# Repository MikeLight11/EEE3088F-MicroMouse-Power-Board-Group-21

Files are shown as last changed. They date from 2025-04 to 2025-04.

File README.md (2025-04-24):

# Micromouse Power Subsystem

## Overview
This repository contains the design files and documentation for the power subsystem of a micromouse robot developed for the EEE3088F 2025 course project. The micromouse is an autonomous robot designed to navigate through and solve mazes efficiently. The power subsystem is responsible for powering the entire micromouse, including battery management, motor control, and regulated power distribution.

## Project Description
The micromouse project consists of four main modules:
- Motherboard (provided)
- Processor (provided)
- Sensing system (provided)
- Power subsystem (this project)

Our power subsystem is designed to meet the following key requirements:
- Power and control 4 motors bidirectionally
- Provide battery monitoring via INA219 on I2C bus
- Charge the battery from 9V input with dual charging modes
- Integrate USB-C with 9V output
- Provide external load switching capabilities
- Deliver regulated 3.3V and 5V outputs
- Include ON/OFF switch with ultra-low power standby mode

## Features
- **Battery Management**: Uses BQ24074 charge controller for efficient Li-Ion battery charging with configurable charging currents (200mA standard, 600mA fast charging)
- **Motor Control**: H-bridges for bidirectional control of up to 4 motors
- **Power Regulation**: Provides stable 3.3V and 5V power rails
- **Load Switching**: Two external load switches capable of handling 1A each
- **Battery Monitoring**: INA219 current/voltage monitoring over I2C
- **Power-saving Mode**: <30μA current draw in OFF state
- **USB-C Integration**: Supports power input through USB-C

## Repository Structure
- `/Docs` - Documentation including the report
- `/Final Schematic and PCB` - KiCad schematic files and PCB design files
- `/Footprint Library` - Contains all imported footprints 
- `/Gerbers` - Production Gerber files
- `/Old Schematics` - Backup KiCad schematic files 
- `/Production files` - Contains the zip file of the Gerbers, the BOM and CPL (JLCPCB Submission files)

## Hardware Specifications
- Dimensions: Maximum 82mm × 60mm
- Battery: 3.7V 800mAh LiPo
- Input Voltage: 9V or USB-C
- Output Voltages: 3.3V (300mA max) and 5V (1.5A max)
- PCB Connector: 2x16 (2.54mm pin pitch) header connecting to the motherboard

## 3D render of PCB
WhatsApp Image 2025-03-28 at 17 49 13_c2ff8d84

## Contributors
- Michael Lighton (LGHMIC003)
- Michael Smith (SMTMIC078)

## Acknowledgments
- University of Cape Town, Department of Electrical Engineering
- EEE3088F course staff

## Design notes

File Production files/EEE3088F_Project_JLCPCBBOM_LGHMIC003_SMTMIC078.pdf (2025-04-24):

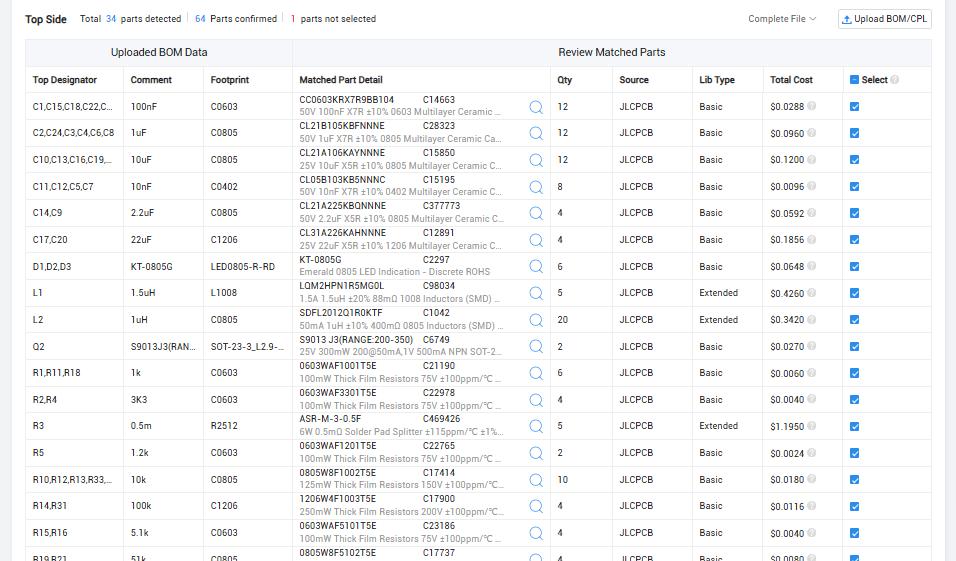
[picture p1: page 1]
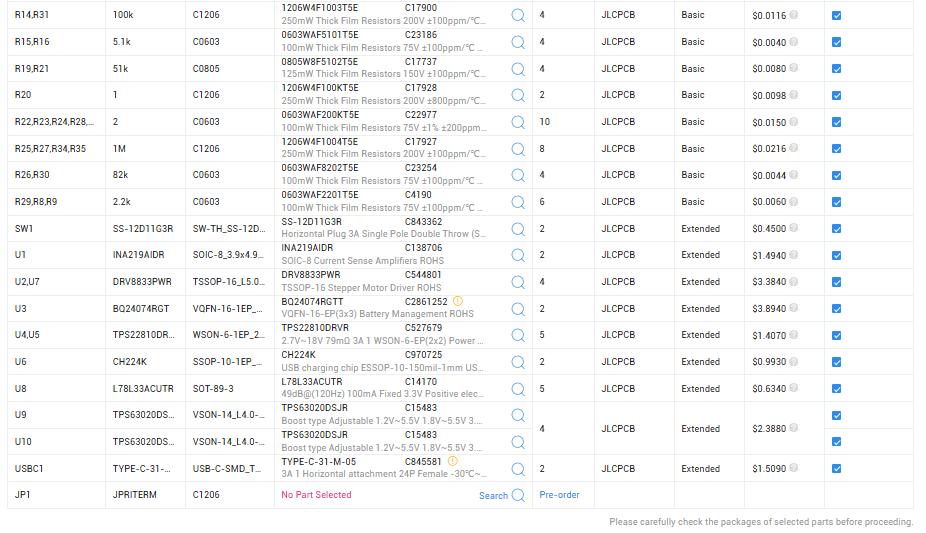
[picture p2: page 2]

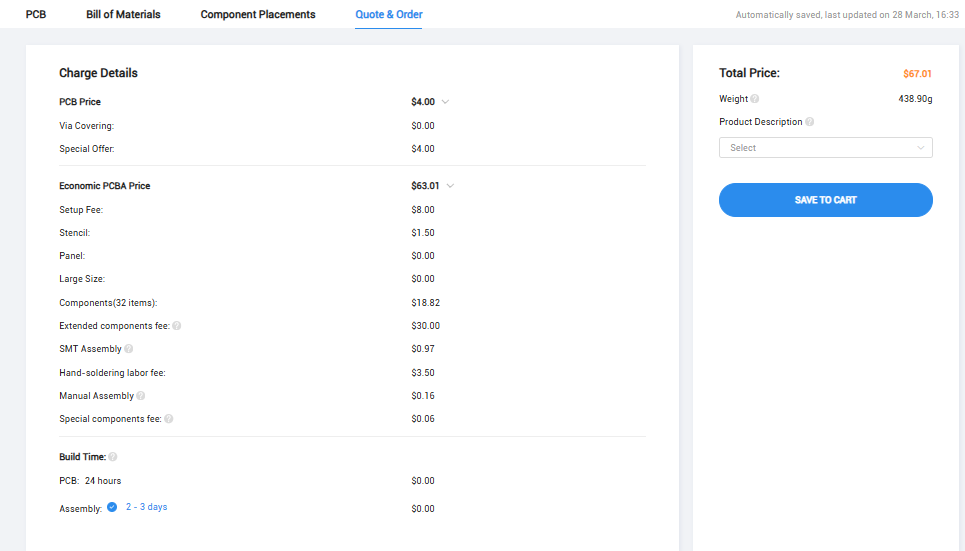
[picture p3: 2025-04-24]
Production files/EEE3088F_Project_JLCPCBacceptance_LGHMIC003_SMTMIC078.png

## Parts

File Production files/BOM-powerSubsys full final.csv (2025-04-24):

Comment | Designator | Footprint | LCSC | Quantity
1uH | L2 | C0805 | C1042 | 1
22uF | C17,C20 | C1206 | C12891 | 2
INA219AIDR | U1 | SOIC-8_3.9x4.9mm_P1.27mm | C138706 | 1
L78L33ACUTR | U8 | SOT-89-3 | C14170 | 1
100nF | C1,C15,C18,C22,C23,C25 | C0603 | C14663 | 6
10nF | C11,C12,C5,C7 | C0402 | C15195 | 4
10uF | C10,C13,C16,C19,C21,C26 | C0805 | C15850 | 6
10k | R10,R12,R13,R33,R7 | C0805 | C17414 | 5
51k | R19,R21 | C0805 | C17737 | 2
100k | R14,R31 | C1206 | C17900 | 2
1M | R25,R27,R34,R35 | C1206 | C17927 | 4
1 | R20 | C1206 | C17928 | 1
1k | R1,R11,R18 | C0603 | C21190 | 3
1.2k | R5 | C0603 | C22765 | 1
KT-0805G | D1,D2,D3 | LED0805-R-RD | C2297 | 3
2 | R22,R23,R24,R28,R32 | C0603 | C22977 | 5
3K3 | R2,R4 | C0603 | C22978 | 2
5.1k | R15,R16 | C0603 | C23186 | 2
82k | R26,R30 | C0603 | C23254 | 2
1uF | C2,C24,C3,C4,C6,C8 | C0805 | C28323 | 6
2.2uF | C14,C9 | C0805 | C377773 | 2
2.2k | R29,R8,R9 | C0603 | C4190 | 3
0.5m | R3 | R2512 | C469426 | 1
TPS22810DRVR | U4,U5 | WSON-6-1EP_2x2mm_P0.65mm_EP1x1.6mm | C527679 | 2
DRV8833PWR | U2,U7 | TSSOP-16_L5.0-W4.4-P0.65-LS6.4-BL | C544801 | 2
S9013 J3(RANGE:200-350) | Q2 | SOT-23-3_L2.9-W1.3-P1.90-LS2.4-BR | C6749 | 1
SS-12D11G3R | SW1 | SW-TH_SS-12D11L3 | C843362 | 1
TYPE-C-31-M-05 | USBC1 | USB-C-SMD_TYPE-C-USB-19 | C845581 | 1
CH224K | U6 | SSOP-10-1EP_3.9x4.9mm_P1mm_EP2.1x3.3mm | C970725 | 1
1.5uH | L1 | L1008 | C98034 | 1
JP RITERM | JP1 | C1206 |  | 1
TPS63020DSJR | U9 | VSON-14_L4.0-W3.0-P0.50-BL-EP_TI_DSJ |  | 1
TPS63020DSJR | U10 | VSON-14_L4.0-W3.0-P0.50-BL-EP_TI_DSJ |  | 1
BQ24074RGT | U3 | VQFN-16-1EP_3x3mm_P0.5mm_EP1.6x1.6mm |  | 1

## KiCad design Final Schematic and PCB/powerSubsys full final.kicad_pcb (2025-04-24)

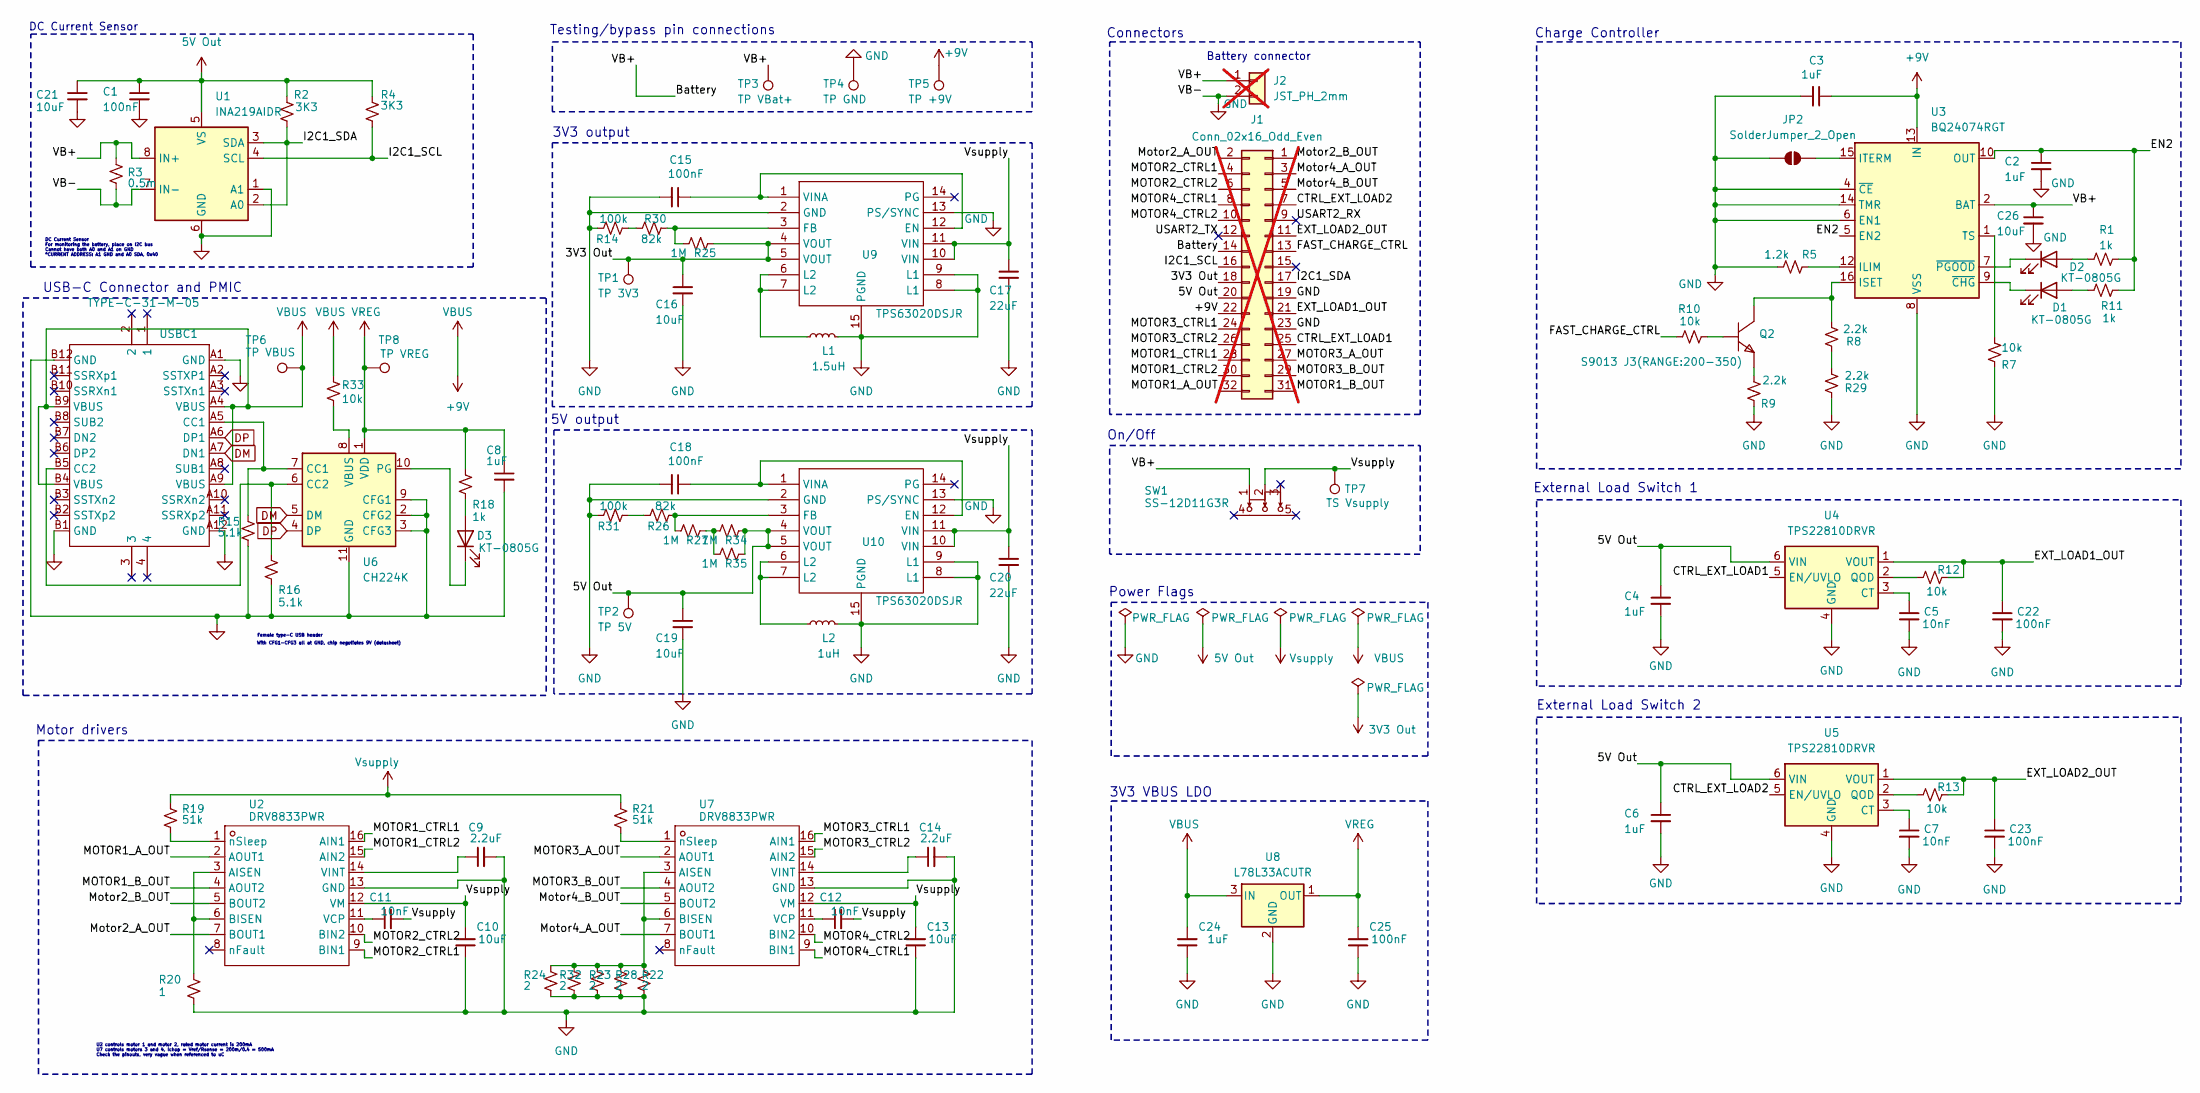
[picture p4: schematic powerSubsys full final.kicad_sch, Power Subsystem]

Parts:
C1, C15, C18, C22, C23, C25: 100nF; C0603; LCSC C14663
C2, C3, C4, C6, C8, C24: 1uF; C0805; LCSC C28323
C5, C7, C11, C12: 10nF; C0402; LCSC C15195
C9, C14: 2.2uF; C0805; LCSC C377773
C10, C13, C16, C19, C21, C26: 10uF; C0805; LCSC C15850
C17, C20: 22uF; C1206; LCSC C12891
D1, D2, D3: KT-0805G; LED0805-R-RD; LCSC C2297
J1: Conn_02x16_Odd_Even; PinHeader_2x16_P2.54mm_Vertical; not fitted
J2: JST_PH_2mm; JST_PH_S2B-PH-K_1x02_P2.00mm_Horizontal; not fitted
JP2: SolderJumper_2_Open; SolderJumper-2_P1.3mm_Open_RoundedPad1.0x1.5mm
L1: 1.5uH; L1008; LCSC C98034
L2: 1uH; C0805; LCSC C1042
Q2: S9013 J3(RANGE:200-350); SOT-23-3_L2.9-W1.3-P1.90-LS2.4-BR; MANUFACTURER PART S9013 J3(RANGE:200-350); LCSC PART NAME NPN 电流:500mA 耐压:25V H档(200-350)
R1, R11, R18: 1k; C0603; LCSC C21190
R2, R4: 3K3; C0603; LCSC C22978
R3: 0.5m; R2512; LCSC C469426
R5: 1.2k; C0603; LCSC C22765
R7, R10, R12, R13, R33: 10k; C0805; LCSC C17414
R8, R9, R29: 2.2k; C0603; LCSC C4190
R14, R31: 100k; C1206; LCSC C17900
R15, R16: 5.1k; C0603; LCSC C23186
R19, R21: 51k; C0805; LCSC C17737
R20: 1; C1206; LCSC C17928
R22, R23, R24, R28, R32: 2; C0603; LCSC C22977
R25, R27, R34, R35: 1M; C1206; LCSC C17927
R26, R30: 82k; C0603; LCSC C23254
SW1: SS-12D11G3R; SW-TH_SS-12D11L3; CURRENT RATING (DC) 3A; VOLTAGE RATING (DC) 125V; MANUFACTURER PART SS-12D11G3R; LCSC PART NAME 柄长3mm 弯插双档 滑动开关
TP1: TP 3V3; TestPoint_Pad_D1.5mm
TP2: TP 5V; TestPoint_Pad_D1.5mm
TP3: TP VBat+; TestPoint_Pad_D1.5mm
TP4: TP GND; TestPoint_Pad_D1.5mm
TP5: TP +9V; TestPoint_Pad_D1.5mm
TP6: TP VBUS; TestPoint_Pad_D1.5mm
TP7: TS Vsupply; TestPoint_Pad_D1.5mm
TP8: TP VREG; TestPoint_Pad_D1.5mm
U1: INA219AIDR; SOIC-8_3.9x4.9mm_P1.27mm; LCSC C138706
U2, U7: DRV8833PWR; TSSOP-16_L5.0-W4.4-P0.65-LS6.4-BL; MANUFACTURER PART DRV8833PWR; LCSC PART NAME DRV8833PWR
U3: BQ24074RGT; VQFN-16-1EP_3x3mm_P0.5mm_EP1.6x1.6mm; LCSC C54313
U4, U5: TPS22810DRVR; WSON-6-1EP_2x2mm_P0.65mm_EP1x1.6mm; LCSC C527679
U6: CH224K; SSOP-10-1EP_3.9x4.9mm_P1mm_EP2.1x3.3mm; LCSC C970725
U8: L78L33ACUTR; SOT-89-3; LCSC C14170
U9, U10: TPS63020DSJR; VSON-14_L4.0-W3.0-P0.50-BL-EP_TI_DSJ; INPUT VOLTAGE 1.8V~5.5V; OUTPUT VOLTAGE 1.2V~5.5V; MANUFACTURER PART TPS63020DSJR; LCSC PART NAME 高效率单电感升降压转换器
USBC1: TYPE-C-31-M-05; USB-C-SMD_TYPE-C-USB-19; CURRENT RATING-POWER 5A; MANUFACTURER PART TYPE-C-31-M-05; LCSC PART NAME Type-C 母

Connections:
3V3 Out: C16.1, J1.18, R25.2, TP1.1, U9.4 (VOUT), U9.5 (VOUT)
5V Out: C1.1, C4.1, C6.1, C19.1, C21.1, J1.20, R2.1, R4.1, R34.2, R35.2, TP2.1, U1.5 (VS), U4.6 (VIN), U5.6 (VIN), U10.4 (VOUT), U10.5 (VOUT)
+9V: C3.1, C24.2, J1.22, R33.1, TP5.1, TP6.1, U3.13 (IN), U8.3 (IN), USBC1.A4 (VBUS), USBC1.A9 (VBUS), USBC1.B4 (VBUS), USBC1.B9 (VBUS)
/Battery: C26.1, J1.14, J2.1, R3.1, SW1.1, TP3.1, U1.8 (IN+), U3.2 (BAT), U3.3 (BAT)
/CTRL_EXT_LOAD1: J1.25, U4.5 (EN/UVLO)
/CTRL_EXT_LOAD2: J1.7, U5.5 (EN/UVLO)
/EN2: C2.1, R1.1, R11.1, U3.5 (EN2), U3.10 (OUT), U3.11 (OUT)
/EXT_LOAD1_OUT: C22.1, J1.21, R12.2, U4.1 (VOUT)
/EXT_LOAD2_OUT: C23.1, J1.11, R13.2, U5.1 (VOUT)
/FAST_CHARGE_CTRL: J1.13, R10.1
/I2C1_SCL: J1.16, R4.2, U1.4 (SCL)
/I2C1_SDA: J1.17, R2.2, U1.2 (A0), U1.3 (SDA)
/MOTOR1_A_OUT: J1.32, U2.2 (AOUT1)
/MOTOR1_B_OUT: J1.31, U2.4 (AOUT2)
/MOTOR1_CTRL1: J1.28, U2.16 (AIN1)
/MOTOR1_CTRL2: J1.30, U2.15 (AIN2)
/MOTOR2_CTRL1: J1.4, U2.9 (BIN1)
/MOTOR2_CTRL2: J1.6, U2.10 (BIN2)
/MOTOR3_A_OUT: J1.27, U7.2 (AOUT1)
/MOTOR3_B_OUT: J1.29, U7.4 (AOUT2)
/MOTOR3_CTRL1: J1.24, U7.16 (AIN1)
/MOTOR3_CTRL2: J1.26, U7.15 (AIN2)
/MOTOR4_CTRL1: J1.8, U7.9 (BIN1)
/MOTOR4_CTRL2: J1.10, U7.10 (BIN2)
/Motor2_A_OUT: J1.2, U2.7 (BOUT1)
/Motor2_B_OUT: J1.1, U2.5 (BOUT2)
/Motor4_A_OUT: J1.3, U7.7 (BOUT1)
/Motor4_B_OUT: J1.5, U7.5 (BOUT2)
/USART2_RX: J1.9
/USART2_TX: J1.12
DM: U6.5 (DM), USBC1.A7 (DN1)
DP: U6.4 (DP), USBC1.A6 (DP1)
GND: C1.2, C2.2, C3.2, C4.2, C5.2, C6.2, C7.2, C8.2, C9.2, C10.1, C13.1, C14.2, C15.2, C16.2, C17.2, C18.2, C19.2, C20.2, C21.2, C22.2, C23.2, C24.1, C25.1, C26.2, J1.19, J1.23, J2.2, JP2.1 (A), L1.2, L2.2, R3.2, R5.1, R7.2, R9.2, R14.1, R15.2, R16.2, R20.2, R22.2, R23.2, R24.2, R28.2, R29.2, R31.1, R32.2, TP4.1, U1.1 (A1), U1.6 (GND), U1.7 (IN-), U2.13 (GND), U3.4 (~CE), U3.6 (EN1), U3.8 (VSS), U3.14 (TMR), U3.17 (VSS), U4.4 (GND), U4.7 (GND), U5.4 (GND), U5.7 (GND), U6.2 (CFG2), U6.3 (CFG3), U6.9 (CFG1), U6.11 (GND), U7.13 (GND), U8.2 (GND), U9.2 (GND), U9.8 (L1), U9.9 (L1), U9.13 (PS/SYNC), U9.15 (PGND), U10.2 (GND), U10.8 (L1), U10.9 (L1), U10.13 (PS/SYNC), U10.15 (PGND), USBC1.A1 (GND), USBC1.A12 (GND), USBC1.B1 (GND), USBC1.B12 (GND); also elsewhere on the board
unnamed: D1.2 (A), R11.2
unnamed: D1.1 (K), U3.9 (~CHG)
unnamed: D2.2 (A), R1.2
unnamed: D2.1 (K), U3.7 (~PGOOD)
unnamed: D3.2 (A), R18.2
unnamed: D3.1 (K), U6.10 (PG)
unnamed: JP2.2 (B), U3.15 (ITERM)
unnamed: L1.1, U9.6 (L2), U9.7 (L2)
unnamed: L2.1, U10.6 (L2), U10.7 (L2)
unnamed: Q2.1 (B), R10.2
unnamed: Q2.3 (C), R8.1, U3.16 (ISET)
unnamed: Q2.2 (E), R9.1
unnamed: R14.2, R30.1
unnamed: R26.1, R31.2
unnamed: R27.2, R34.1, R35.1
unnamed: R8.2, R29.1
unnamed: R20.1, U2.3 (AISEN), U2.6 (BISEN)
unnamed: C11.1, U2.11 (VCP)
unnamed: C9.1, U2.14 (VINT)
unnamed: R19.2, U2.1 (nSleep)
unnamed: R5.2, U3.12 (ILIM)
unnamed: R7.1, U3.1 (TS)
unnamed: C5.1, U4.3 (CT)
unnamed: R12.1, U4.2 (QOD)
unnamed: C7.1, U5.3 (CT)
unnamed: R13.1, U5.2 (QOD)
unnamed: R15.1, U6.7 (CC1), USBC1.A5 (CC1)
unnamed: R16.1, U6.6 (CC2), USBC1.B5 (CC2)
unnamed: R33.2, U6.8 (VBUS)
unnamed: R22.1, R23.1, R24.1, R28.1, R32.1, U7.3 (AISEN), U7.6 (BISEN)
unnamed: C12.1, U7.11 (VCP)
unnamed: C14.1, U7.14 (VINT)
unnamed: R21.2, U7.1 (nSleep)
unnamed: C15.1, U9.1 (VINA), U9.12 (EN)
unnamed: R25.1, R30.2, U9.3 (FB)
unnamed: C18.1, U10.1 (VINA), U10.12 (EN)
unnamed: R26.2, R27.1, U10.3 (FB)
VREG: C8.1, C25.2, R18.1, TP8.1, U6.1 (VDD), U8.1 (OUT)
Vsupply: C10.2, C11.2, C12.2, C13.2, C17.1, C20.1, R19.1, R21.1, SW1.2, TP7.1, U2.12 (VM), U7.12 (VM), U9.10 (VIN), U9.11 (VIN), U10.10 (VIN), U10.11 (VIN)

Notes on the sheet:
Battery connector
3V3 VBUS LDO
U2 controls motor 1 and motor 2, rated motor current is 200mA U7 controls motors 3 and 4, Ichop = Vref/Rsense = 200m/0.4 = 500mA Check the pinouts, very vague when referenced to uC
DC Current Sensor
External Load Switch 2
Connectors
DC Current Sensor For monitoring the battery, place on I2C bus Cannot have both A0 and A1 on GND *CURRENT ADDRESS: A1 GND and A0 SDA, 0x40
Power Flags
Motor drivers
Charge Controller
Female type-C USB header
3V3 output
On/Off
5V output
Testing/bypass pin connections
With CFG1-CFG3 all at GND, chip negotiates 9V (datasheet)
External Load Switch 1
USB-C Connector and PMIC

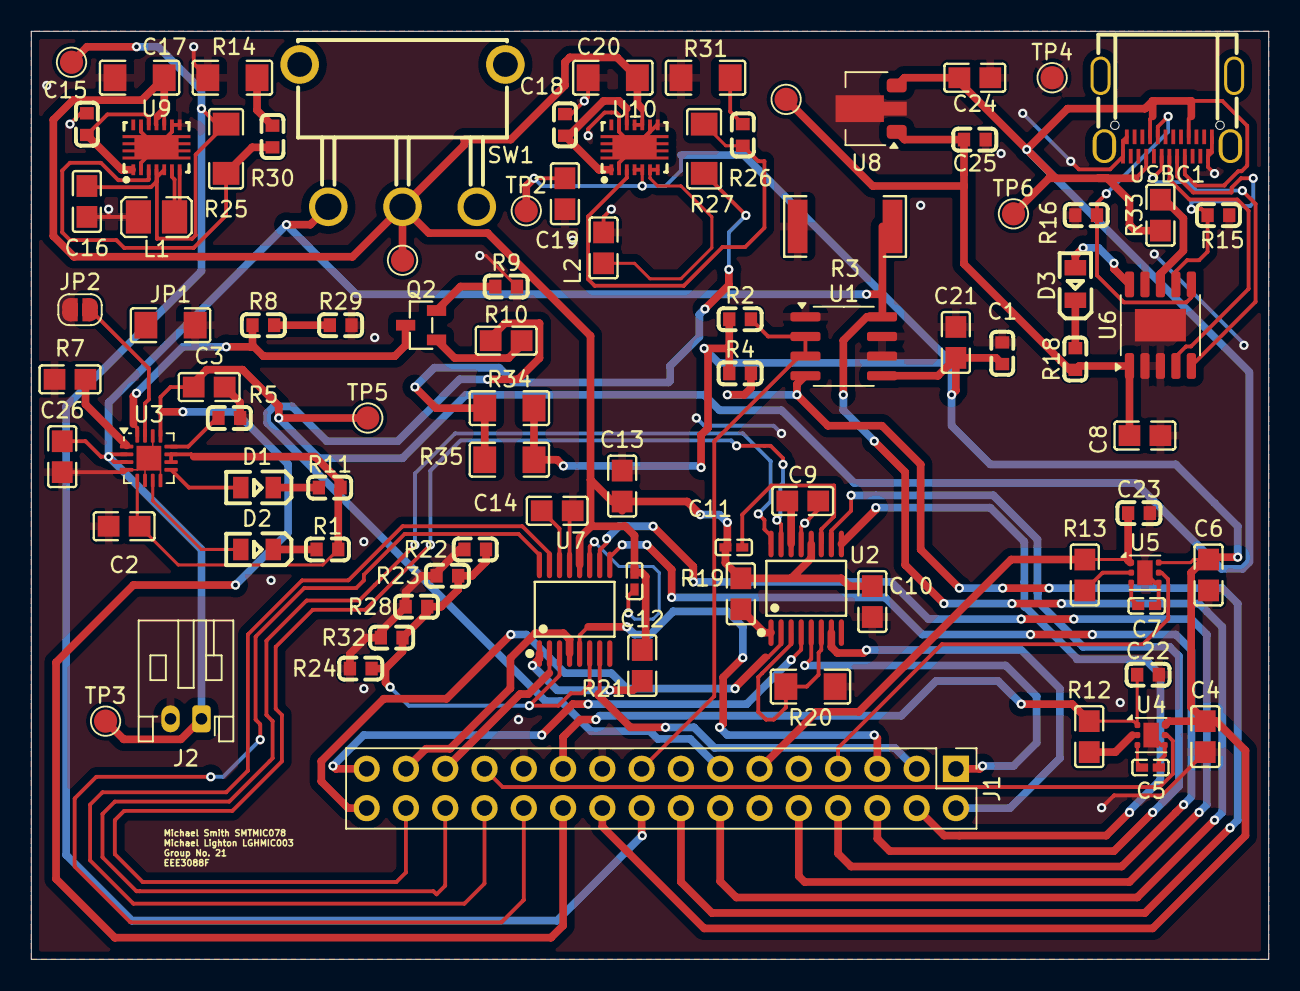
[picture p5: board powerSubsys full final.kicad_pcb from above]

Board: 2 copper layers, 80.0 x 60.0 mm, 89 parts (0 on the bottom side), 70 nets.

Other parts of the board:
JP1: JP RITERM; C1206

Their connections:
GND: JP1.1 (A); also elsewhere on the board

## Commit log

2025-03-19 Add files via upload
    Rev 1 of Kicad design:
    Created file
    Added connectors
    Added connector headings
    Started DC current monitor functionality
    [powerSubsys.kicad_sch]
2025-03-21 Add files via upload
    - Progressed INA219 current sensor
    - Set new I2C address config to not conflict with sensor module
    - Neatened up design
    [powerSubsys.kicad_sch]
2025-03-22 Added the charging controller
    [powerSubsys.kicad_sch]
2025-03-23 Added: Charge Controller and Load Switches
    [powerSubsys.kicad_sch]
2025-03-23 Add files via upload
    Added: USB-C female header and PWIC
    [powerSubsys (2).kicad_sch]
2025-03-24 Cleaning and addition
    Cleaned up schematic
    Added H-bridge IC
    [powerSubsys.kicad_sch]
2025-03-25 Added motor drivers
    [powerSubsys.kicad_sch]
2025-03-25 Deleted powerSubsys (2).kicad_sch
    [powerSubsys (2).kicad_sch]
2025-03-25 Added: Voltage converters and Switch
    [powerSubsys full.kicad_sch]
2025-03-26 Added 3V3 and 5V Output
    [powerSubsys full.kicad_sch]
2025-03-26 Updated the switch design
    [powerSubsys full.kicad_sch]
2025-03-26 Updated the load switches
    [powerSubsys full.kicad_sch]
2025-03-26 Added power flags
    [powerSubsys full final.kicad_sch]
2025-03-27 Kicad footies
2025-03-27 Added voltage regulator
    [powerSubsys full final.kicad_sch]
2025-03-28 this is a zip of the schematic and pcb
2025-04-21 Create Schematics
2025-04-21 Update and rename powerSubsys full final.kicad_sch to Schematics/powerSubsys full final.kicad_sch
    [powerSubsys full final.kicad_sch]
2025-04-21 Update and rename powerSubsys full.kicad_sch to Schematics/powerSubsys full.kicad_sch
    [powerSubsys full.kicad_sch]
2025-04-21 Update and rename powerSubsys.kicad_sch to Schematics/powerSubsys.kicad_sch
    [powerSubsys.kicad_sch]
2025-04-21 Update and rename powerSubsys full final.kicad_pcb to Final KiCad files/powerSubsys full final.kicad_pcb
    [powerSubsys full final.kicad_pcb]
2025-04-21 Rename powerSubsys full final.kicad_prl to Final KiCad files/powerSubsys full final.kicad_prl
2025-04-21 Rename powerSubsys full final.csv to Final KiCad files/powerSubsys full final.csv
    [powerSubsys full final.csv]
2025-04-21 Rename powerSubsys full final.kicad_pro to Final KiCad files/powerSubsys full final.kicad_pro
2025-04-21 Update and rename powerSubsys full final.net to Final KiCad files/powerSubsys full final.net
2025-04-21 Update and rename powerSubsys full.kicad_sch-bak to Final KiCad files/powerSubsys full.kicad_sch-bak
2025-04-21 Update and rename powerSubsys full final.kicad_sch to powerSubsys full final.kicad_sch
    [powerSubsys full final.kicad_sch]
2025-04-21 Update and rename powerSubsys full.kicad_sch to powerSubsys full.kicad_sch
    [powerSubsys full.kicad_sch]
2025-04-21 Update and rename powerSubsys.kicad_sch to powerSubsys.kicad_sch
    [powerSubsys.kicad_sch]
2025-04-21 Rename Library.pretty.zip to Footprint Libary/Library.pretty.zip
2025-04-21 Rename Final Power System.zip to Final KiCad files/Final Power System.zip
2025-04-22 Folder that contains imported footprints from JLCPCB
